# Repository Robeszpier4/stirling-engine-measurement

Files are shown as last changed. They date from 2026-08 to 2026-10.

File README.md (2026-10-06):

Ezen NYÁK lap (Nyomtatott áramköri lap) egy strling motor frekvenicájának és a két lapja közötti hőmérséklet különbség mérésére készült. 3 darab feszültségosztón alapuló termisztoros hőmérsékletmérő került elhelyezésre (ezek közül kettő a két lap hőmérsékletét és egy a környezet hőmérsékletét méri), melyeket egy Raspberry Pi Pico 2 ADC-je (Analog to digital converter) olvas ki. Továbbá egy a mikrokontrollerre kötött rés-opto modullal méri a berendezés a Striling motor frekvenciáját. A NYÁK-ra elhelyezésre került 2 darab LED is, melyet a mérés során különböző a mérést elősegítő feladatokra lehet használni.

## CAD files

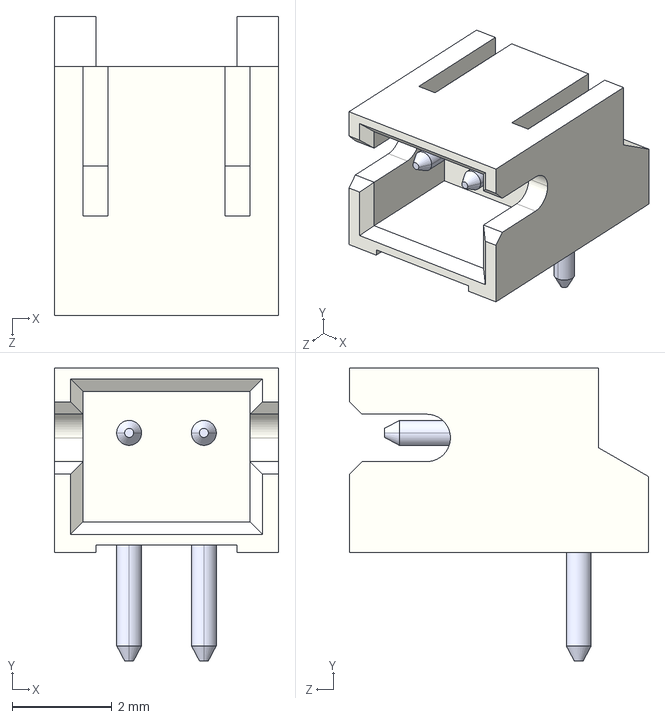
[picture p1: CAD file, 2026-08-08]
PCB/3D/S2B-ZR_LF__SN_.step
4.50 x 5.87 x 6.00 mm

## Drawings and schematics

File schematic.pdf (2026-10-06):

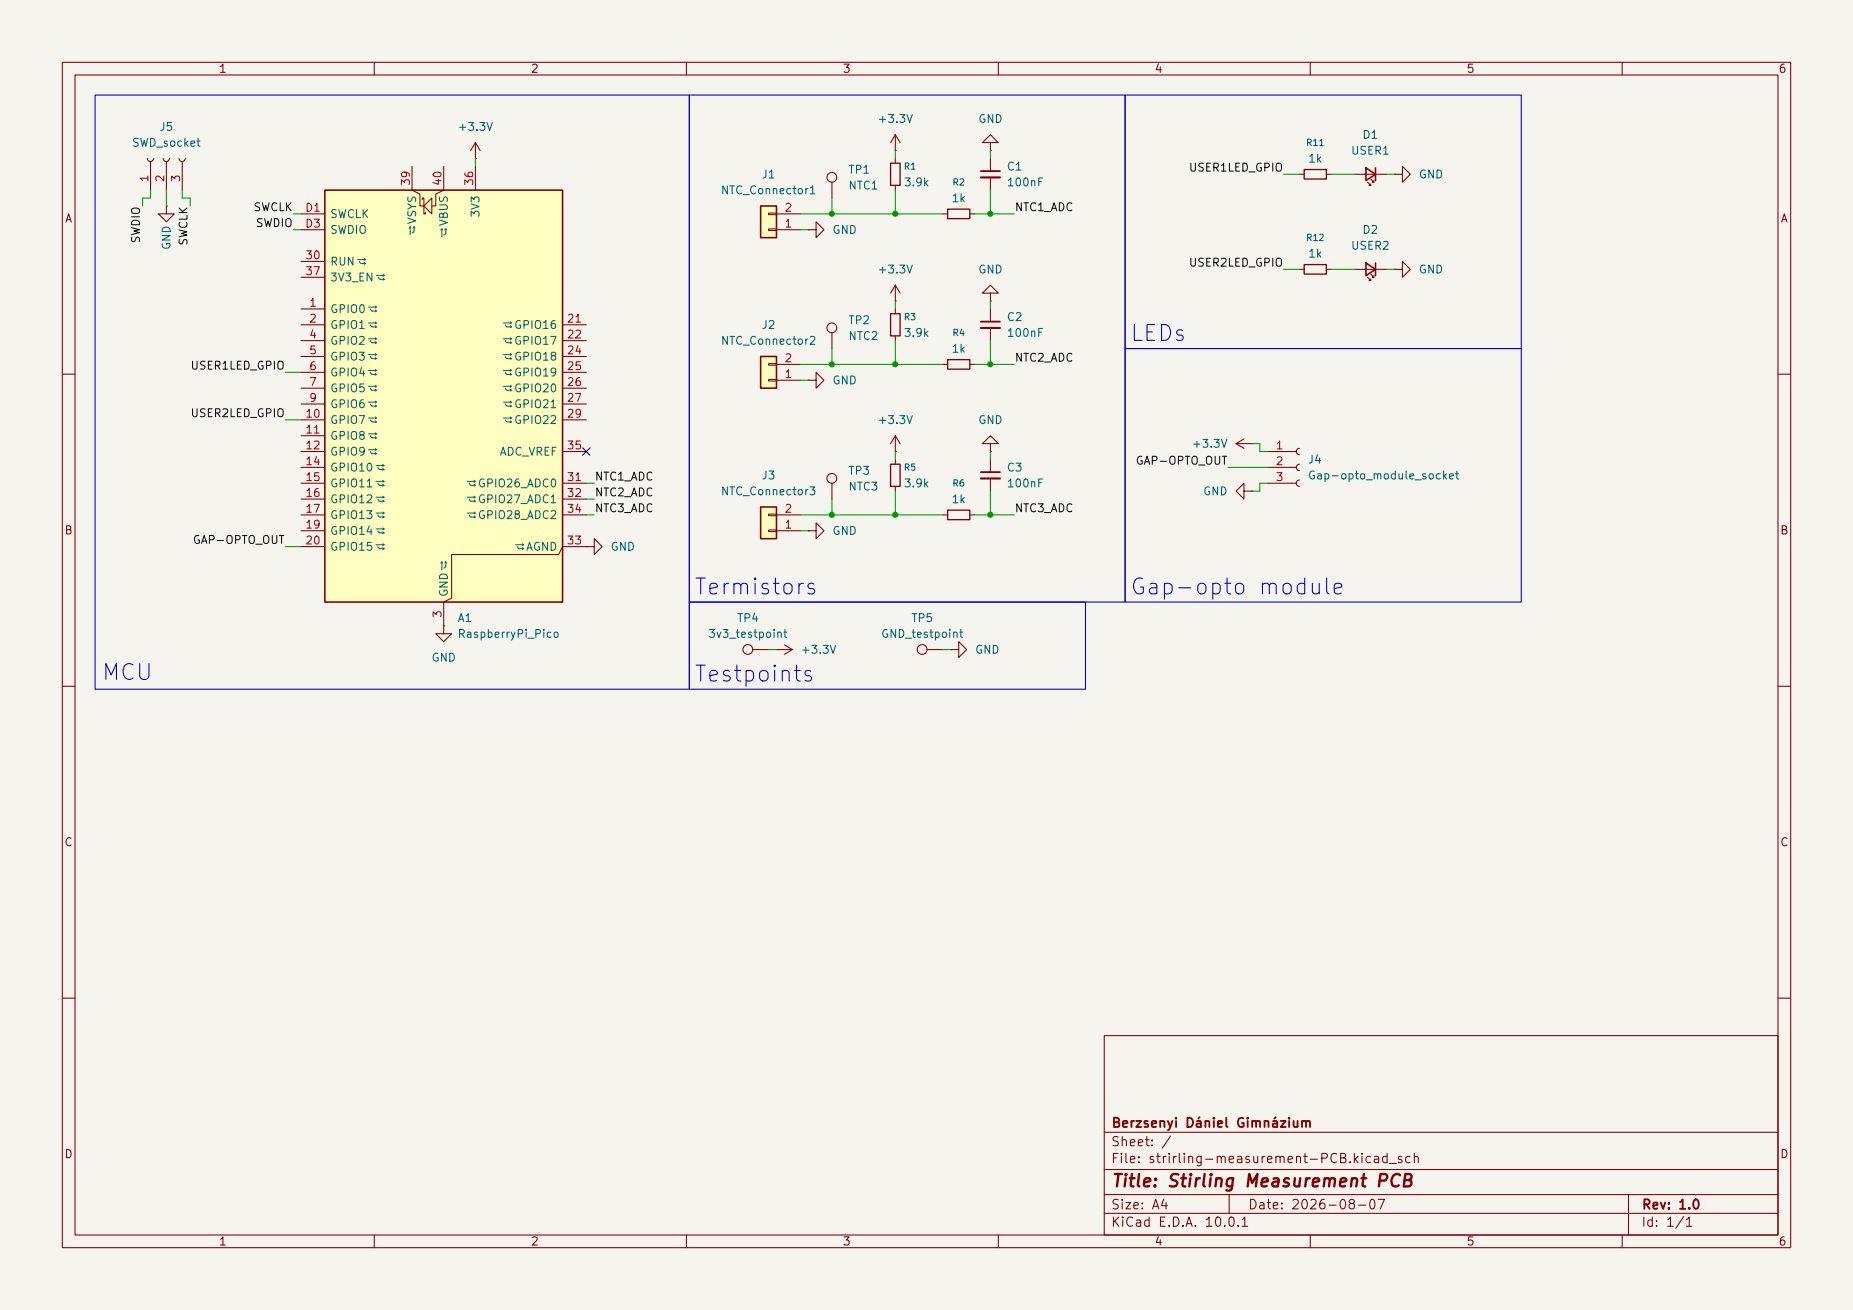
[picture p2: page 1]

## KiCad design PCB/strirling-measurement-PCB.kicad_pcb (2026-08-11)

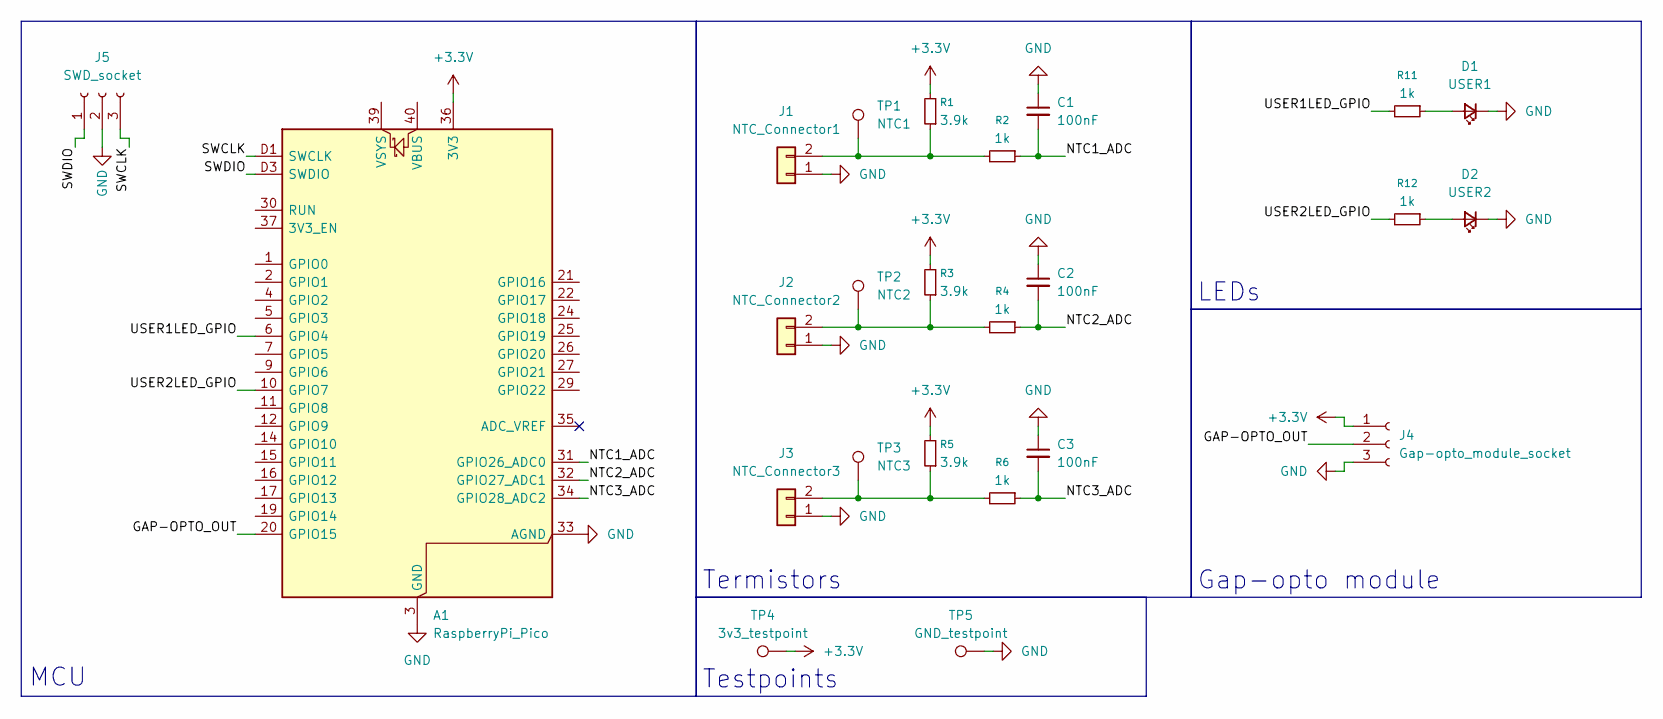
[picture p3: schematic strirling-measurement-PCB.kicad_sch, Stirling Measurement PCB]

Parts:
A1: RaspberryPi_Pico; RaspberryPi_Pico_SMD_HandSolder
C1, C2, C3: 100nF; C_0402_1005Metric
D1: USER1; LED_D5.0mm
D2: USER2; LED_D5.0mm
J1: NTC_Connector1; JST_S2B-ZR_LF__SN_
J2: NTC_Connector2; JST_S2B-ZR_LF__SN_
J3: NTC_Connector3; JST_S2B-ZR_LF__SN_
J4: Gap-opto_module_socket; gap-opto_module
J5: SWD_socket; swd_header
R1, R3, R5: 3.9k; R_0603_1608Metric
R2, R4, R6: 1k; R_0402_1005Metric
R11, R12: 1k; R_0805_2012Metric
TP1: NTC1; TestPoint_Pad_2.0x2.0mm
TP2: NTC2; TestPoint_Pad_2.0x2.0mm
TP3: NTC3; TestPoint_Pad_2.0x2.0mm
TP4: 3v3_testpoint; TestPoint_Pad_2.0x2.0mm
TP5: GND_testpoint; TestPoint_Pad_2.0x2.0mm

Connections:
+3.3V: A1.36 (3V3), J4.1, R1.2, R3.2, R5.2, TP4.1 (1_1)
/GAP-OPTO_OUT: A1.20 (GPIO15), J4.2
/NTC1_ADC: A1.31 (GPIO26_ADC0), C1.2, R2.1
/NTC2_ADC: A1.32 (GPIO27_ADC1), C2.2, R4.1
/NTC3_ADC: A1.34 (GPIO28_ADC2), C3.2, R6.1
/SWCLK: A1.D1 (SWCLK), J5.3
/SWDIO: A1.D3 (SWDIO), J5.1
/USER1LED_GPIO: A1.6 (GPIO4), R11.2
/USER2LED_GPIO: A1.10 (GPIO7), R12.2
GND: A1.3 (GND), A1.8 (GND), A1.13 (GND), A1.18 (GND), A1.23 (GND), A1.28 (GND), A1.33 (AGND), A1.38 (GND), A1.D2 (GND), C1.1, C2.1, C3.1, D1.1 (K), D2.1 (K), J1.1, J2.1, J3.1, J4.3, J5.2, TP5.1 (1_1)
unnamed: D1.2 (A), R11.1
unnamed: D2.2 (A), R12.1
unnamed: J1.2, R1.1, R2.2, TP1.1 (1_1)
unnamed: J2.2, R3.1, R4.2, TP2.1 (1_1)
unnamed: J3.2, R5.1, R6.2, TP3.1 (1_1)

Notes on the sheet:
Gap-opto module
Testpoints
MCU
Termistors
LEDs

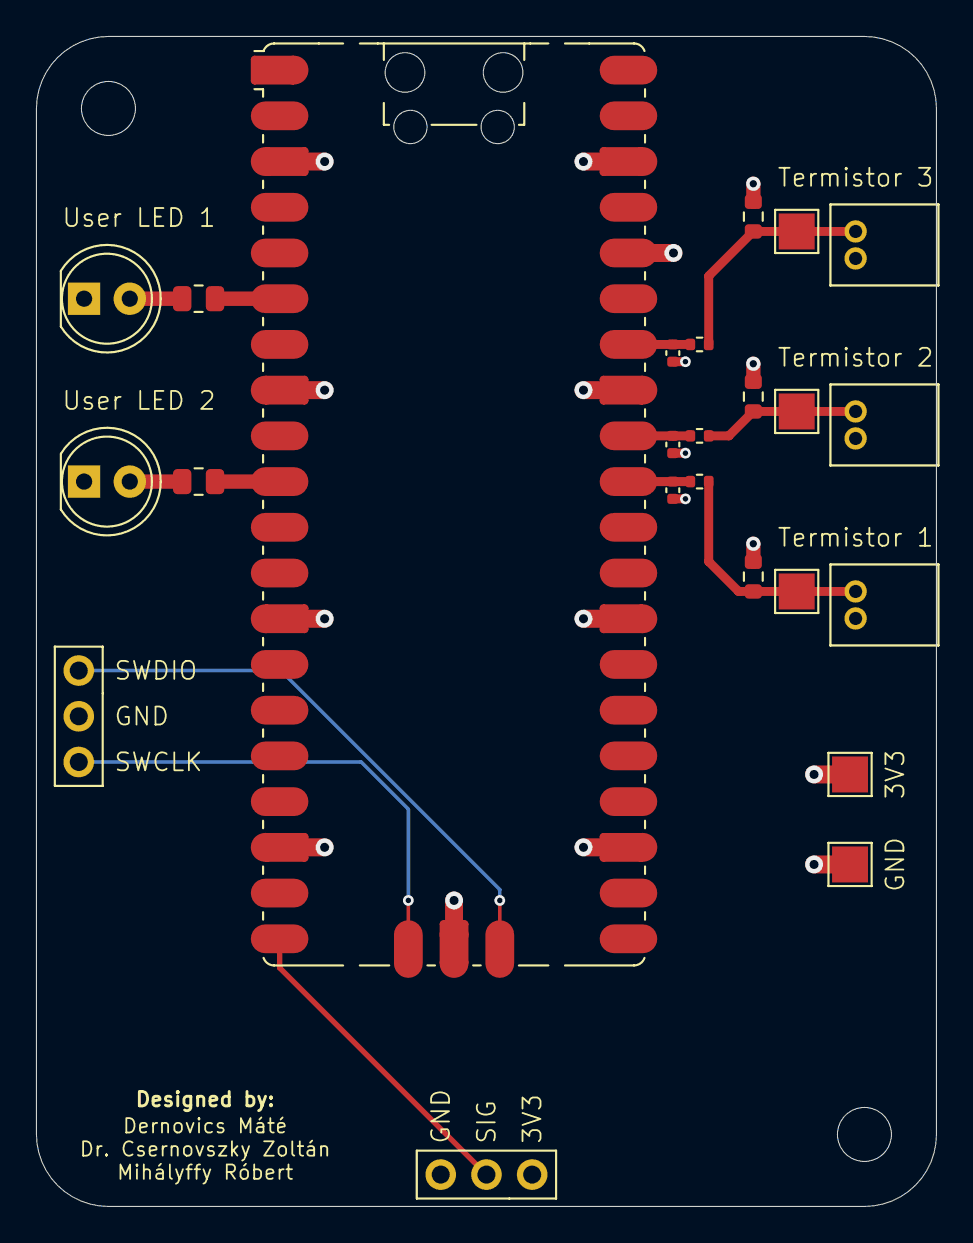
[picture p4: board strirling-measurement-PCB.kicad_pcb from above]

Board: 4 copper layers, 50.0 x 65.0 mm, 24 parts (0 on the bottom side), 15 nets.

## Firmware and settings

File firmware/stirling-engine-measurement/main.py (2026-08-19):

from machine import ADC, Pin
import time
import math

# convert temperature from ADC
def convertTemperature(ADCvalue, R0, beta, rReference, T0):
    rNTC = (rReference) / ((65535/ADCvalue) - 1)

    temperature = 1 / ((1 / T0) + (1 / beta) * math.log(rNTC / R0))

    return temperature

# samples for 20 ms, returns the average of the samples
def readNTC(NTCadc):
    startMs = time.ticks_ms()
    numOfSamples = 0
    ADCsum = 0

    while time.ticks_diff(time.ticks_ms(), startMs) < 20:
        ADCsum += NTCadc.read_u16()
        numOfSamples += 1

    avgADC = ADCsum / numOfSamples

    return convertTemperature(avgADC, 10000, 3380, 3900, 298.15)

def optoInterruptHandler(pin):
    global firstInterruptReceived, lastInterruptMS, freqPacket

    if firstInterruptReceived == True:
        currentTimeMS = time.ticks_ms()

        if time.ticks_diff(currentTimeMS, lastInterruptMS) > 20:
            freq = 1 / (time.ticks_diff(currentTimeMS, lastInterruptMS) / 1000) # calculating freq (1 / sec)
    
            freqTimestamp = (currentTimeMS + lastInterruptMS) / 2 # timestamp for the freq, avg of the last and the current time
    
            lastInterruptMS = currentTimeMS
    
            freqPacket[0] = freqTimestamp
            freqPacket[1] = freq

            userLed1.toggle()
    else:
        lastInterruptMS = time.ticks_ms()
        firstInterruptReceived = True

        userLed1.toggle()
            

NTC1 = ADC(Pin(26))
NTC2 = ADC(Pin(27))
NTC3 = ADC(Pin(28))

userLed1 = Pin(4, Pin.OUT)
userLed2 = Pin(7, Pin.OUT)

firstInterruptReceived = False
lastInterruptMS = 0
freqPacket = [-1.0, -1.0] # timeMS, freq

opto = Pin(15, Pin.IN)
opto.irq(trigger=Pin.IRQ_RISING, handler=optoInterruptHandler)

while True:
    # measuring temperature
    userLed2.value(1)

    NTC1_temp = readNTC(NTC1)
    NTC1_tempMs = time.ticks_ms() - 10

    NTC2_temp = readNTC(NTC2)
    NTC2_tempMs = time.ticks_ms() - 10

    NTC3_temp = readNTC(NTC3)
    NTC3_tempMs = time.ticks_ms() - 10

    userLed2.value(0)

    print(f"start|{NTC1_temp}#{NTC1_tempMs}|{NTC2_temp}#{NTC2_tempMs}|{NTC3_temp}#{NTC3_tempMs}|{freqPacket[1]}#{freqPacket[0]}|stop")

    time.sleep_ms(1000)

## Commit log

2026-10-06 schematic pdf added
2026-10-06 excel fix
    [dataparsing1.xlsx]
2026-10-06 excel fix 2
    [dataparsing1.xlsx]
